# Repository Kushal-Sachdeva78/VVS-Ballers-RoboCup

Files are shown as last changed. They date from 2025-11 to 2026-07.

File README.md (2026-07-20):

<p align="center">
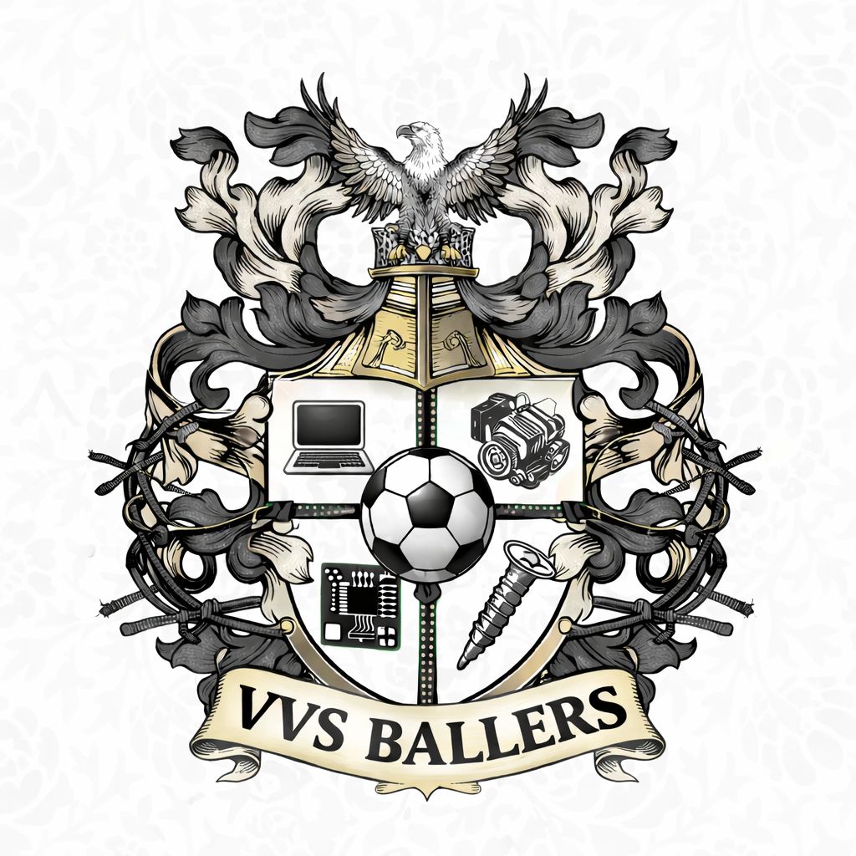
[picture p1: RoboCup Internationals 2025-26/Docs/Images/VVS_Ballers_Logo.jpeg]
VVS Ballers
  
</p>

<h1 align="center">VVS Ballers: RoboCupJunior Soccer</h1>

<p align="center">
  Autonomous RoboCupJunior Soccer robots by Team VVS Ballers, designed and iterated
  across multiple seasons, from EV3 regional robots to a custom Teensy-based
  international platform.<br>
  Firmware (C++) · multi-board electronics (KiCad) · mechanical design (Fusion 360).
</p>

<p align="center">
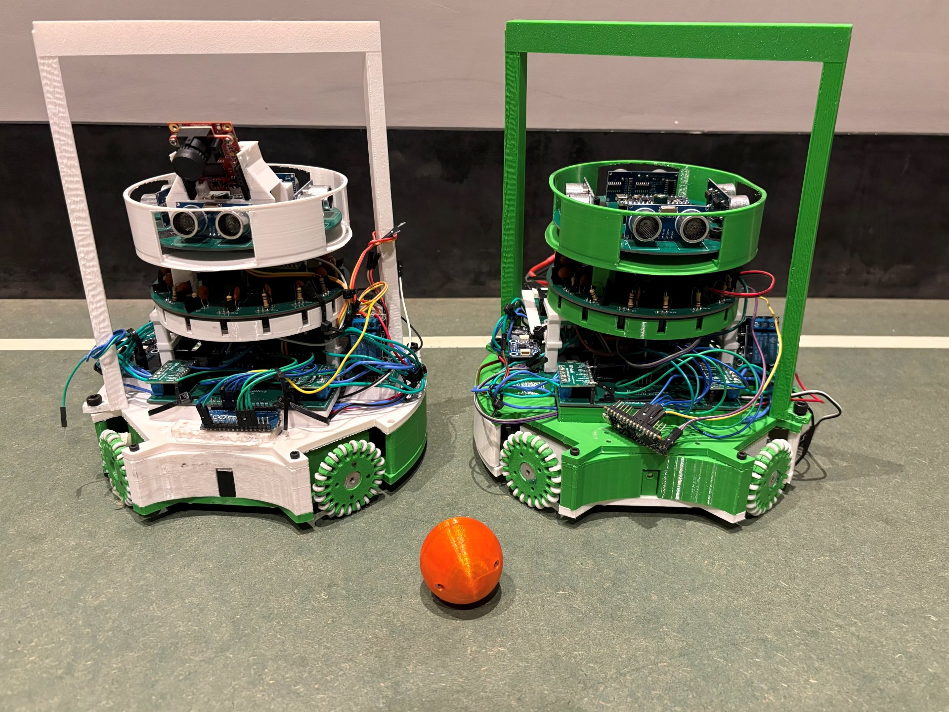
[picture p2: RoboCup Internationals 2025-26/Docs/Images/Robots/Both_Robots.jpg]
The two Internationals 2025-26 robots with the IR ball
  
</p>

---

## Results

- **RoboCup 2026, Incheon, South Korea (International): 9th place, RoboCupJunior Soccer (IR League).** Two self-built robots, designed, wired, and programmed by a team of two.
- **RoboCupJunior India, 2025-26 season**: came up through the Indian regional and national rounds to qualify for RoboCup 2026. The trophy and finals footage from the national event are in the [Nationals gallery](RoboCup%20Nationals%202025-26/Gallery).

## Press and media

- [Two Students, Two Self-Built Robots, And A 9th-Place Finish At The Robot "World Cup"](https://www.republicworld.com/sports/two-students-two-self-built-robots-and-a-ninth-place-finish-at-the-robot-world-cup-2026-07-14-132303) (Republic World, July 2026)
- [Team Instagram](https://www.instagram.com/vvs_ballers) - Robot builds, competition footage, and event coverage

---

## Seasons

| Season | What's inside |
|---|---|
| **[RoboCup Internationals 2025-26](RoboCup%20Internationals%202025-26/)** ⭐ *current* | Two autonomous Soccer-Infrared robots (attacker + defender): a Teensy 4.1 multi-board stack with an IR ball ring, line ring, ultrasonic, OpenMV goal camera, and 48 V solenoid kicker. Firmware + KiCad PCBs + Fusion CAD. |
| **[RoboCup Nationals 2025-26](RoboCup%20Nationals%202025-26/)** | Nationals build: EV3 robot program (HiTechnic IR seeker and compass), an Arduino relay-driven solenoid kicker, 3D-printed chassis parts, the season poster, and the trophy and finals gallery. |
| **[RoboCup Regionals 2025-26](RoboCup%20Regionals%202025-26/)** | EV3 holonomic robot (diamond omni drive, dual underside colour sensors, side IR distance, IR seeker, compass heading hold) + an Arduino ultrasonic-triggered kicker + printable parts + poster. |
| **[RoboCup 2024-25](RoboCup%202024-25/)** | Prior season: international Team Description Paper, posters, and earlier EV3 reference designs. |

> The **Internationals 2025-26** robots are the current flagship, and the rest of this
> page focuses on them. The full detail lives in that folder's
> **[detailed README](RoboCup%20Internationals%202025-26/README.md)** and a complete
> **[technical deep-dive](RoboCup%20Internationals%202025-26/Docs/HOW_IT_WORKS.md)**.
> Competition media: **[TDP](RoboCup%20Internationals%202025-26/Docs/TDP.md)** ·
> **[poster](RoboCup%20Internationals%202025-26/Docs/RoboCup_Internationals_Poster.png)** ·
> **[TDP video](https://github.com/Kushal-Sachdeva78/VVS-Ballers-RoboCup/releases/download/internationals-2025-26-media/VVS_Ballers_TDP_Video.mp4)** ·
> **[photo gallery](RoboCup%20Internationals%202025-26/Docs/Images)**.
>
> Code-span paths below (e.g. `Firmware/Attacker`) are relative to
> [`RoboCup Internationals 2025-26/`](RoboCup%20Internationals%202025-26/).

### Earlier-season highlights

- **Regionals 2025-26 (EV3):** EV3 motors driving omni wheels in a **diamond** layout;
  underside colour sensors for white-line and goal-area avoidance; side IR sensors for
  walls; an IR seeker for ball tracking; and a compass for heading correction. An
  external Arduino kicker (TB6612FNG H-bridge + gearmotor, ultrasonic ball detect)
  steps through kick, hold, retract, and cooldown phases.
- **Nationals 2025-26 (EV3):** the same EV3 sensing platform, upgraded with a
  relay-driven solenoid kicker triggered by an ultrasonic capture sensor. The custom
  Teensy and KiCad electronics stack was developed next, for the Internationals robots.

---

## Internationals 2025-26: the robots at a glance

Both robots share one electronics stack and one chassis; only the role firmware on
the main board differs.

| | Attacker | Defender (goalkeeper) |
|---|---|---|
| Job | Win the ball, aim, and shoot the open corner | Hold the goal mouth and clear the ball |
| Main firmware | `Firmware/Attacker/Attacker_Chase_Aim_Kick_Line` | `Firmware/Defender/Defender_Full` |
| Ball | IR ring (16 sensors) | IR ring |
| Staying in bounds | **Line ring + ultrasonic fused** boundary escape | **Line** keeps it on the goal-area ("D") line; ultrasonic cross-check |
| Goal / aim | OpenMV camera to open-corner bearing | (camera optional) |
| Kicker | 48 V solenoid, camera-gated | Short clearing kick |

## Electronics: the boards

A **multi-board design**: each subsystem has its own microcontroller, and the boards
talk to the main board over compact **UART links** (CRC-8-framed, bar the plain-ASCII
IR link), keeping the fast sensor loops off the main control CPU.

| Board | MCU | Does | KiCad | Firmware |
|---|---|---|---|---|
| **Main** | Teensy 4.1 | Drive (4x DRV8263H), BNO055 IMU, capture sensor, kicker relay, all links | `PCB/Main` | `Firmware/Attacker`, `Firmware/Defender` |
| **IR ring** | Teensy 4.1 | 16x TSSP58038 for ball bearing and distance | `PCB/IR` | `Firmware/IR_Ball_Sensor` |
| **Line ring** | Teensy 4.1 | 4x QTR-MD-05A (18 ch) for white-line detection | `PCB/Line` | `Firmware/Line_Sensor` |
| **Ultrasonic** | Arduino Nano Every | 4x HC-SR04 for wall distances | `PCB/Ultrasonic` | `Firmware/Ultrasonic` |
| **Camera** | OpenMV H7 | Goal / keeper / open-corner vision | - | `Firmware/Camera` |
| **Power** | - | 12 V / 5 V / 3.3 V rails + 48 V solenoid boost | `PCB/Power` | - |
| **Motor-current** (optional) | Arduino Nano Every | DRV8263H stall / over-current watchdog | - | `Firmware/Motor_Current` |

Human-readable wiring PDFs for the Main, Power, IR, and Line boards are in
**[`PCB/Wiring/`](RoboCup%20Internationals%202025-26/PCB/Wiring)**.

## How it plays: design choices vs. the game

Everything is built around what actually wins (and loses) a RoboCupJunior Soccer
match. (A goal counts when the ball touches the **back wall of the goal**; touching a
wall or driving fully into the marked penalty area is an **out-of-bounds penalty**.)

- **Score in the goal.** The IR ring gives the ball's bearing; the main board chases
  it with an omni-wheel drive held straight by a BNO055 heading PID. Once the ball is
  captured, the OpenMV camera finds the goal, picks the **open corner** (dodging the
  keeper), and the chassis turns in place until that corner is dead ahead before the
  solenoid fires. Aiming for the open corner instead of the goal centre is how you
  beat a keeper.

- **Never cross the line (the expensive mistake).** The attacker treats a side as the
  field boundary **only when the line ring and the ultrasonics agree** (white line
  seen *and* wall within 300 mm), then flees away from it. Two independent sensors
  must concur, so one noisy reading can't make the robot dart out of bounds.

- **Keep the keeper on its line, not inside the box.** No robot may be *fully* inside
  the penalty area, so the defender uses the line ring to ride the **edge of the goal
  area ("the D")** while tracking the ball laterally and clearing it on contact.

- **Stay legal in the Infrared league.** IR-emitting rangefinders (ToF, LiDAR, IR
  distance sensors) are **banned** because they'd swamp other robots' IR ball
  sensors. That is why walls are ranged with **ultrasonic** HC-SR04s here, not IR.

- **Power within the rules.** The rules cap robot power at **48 V DC**; the solenoid
  kicker runs from a 48 V boost converter (right at the legal ceiling, for the hardest
  legal kick) while logic and motors run from 3.3 V / 5 V / 12 V rails.

- **Referee start/stop.** The main board pins out the RoboCupJunior **Communication
  Module** GO/STOP inputs, with firmware support toggled via `USE_COMMS` in the
  defender build.

The binary inter-board links (ultrasonic, line, camera to main) are short frames, each
guarded by an identical **CRC-8 (poly 0x07)**; the IR link is plain delimited ASCII.
Full byte-level layouts are in the
[technical deep-dive](RoboCup%20Internationals%202025-26/Docs/HOW_IT_WORKS.md).

## Team

| Member | Roles |
|---|---|
| **Kushal Sachdeva** (Team Leader) | Electrical, Software & CAD |
| **Darsh Goel** | Mechanical & CAD |

Region: **India** · League: **RoboCupJunior Soccer Infrared**

## Sponsors

Our thanks to **Amazon · DLF · Havells · OpenMV · Magnum Ventures · Budtree
Management**, and to our mentors, school, and the RoboCup Junior community for their
support.

## Related projects

- [K.A.D-Ballers-Genius-Olympiad](https://github.com/Kushal-Sachdeva78/K.A.D-Ballers-Genius-Olympiad): our mecanum-drive robot for the GENIUS Olympiad robotics competition
- More at [github.com/Kushal-Sachdeva78](https://github.com/Kushal-Sachdeva78)

## License

Released under the **MIT License**; see [`LICENSE`](LICENSE).
© 2026 VVS Ballers (Kushal Sachdeva, Darsh Goel). You're welcome to learn from and
build on this work; please keep the attribution.

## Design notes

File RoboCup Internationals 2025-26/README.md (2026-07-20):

<p align="center">
  VVS Ballers
</p>

<h1 align="center">VVS Ballers — RoboCupJunior Soccer (Internationals 2025-26)</h1>

<p align="center">
  Two fully autonomous robots — an <b>attacker</b> and a <b>defender</b> — for the
  <b>RoboCupJunior Soccer Infrared</b> (formerly Lightweight) league.<br>
  Firmware(C++) · multi-board electronics (KiCad) · mechanical design (Fusion 360).
</p>

<p align="center">
  The two robots — one white, one green — facing off over the IR ball
</p>

---

## About

This folder is the **Internationals 2025-26** season of the VVS Ballers
RoboCupJunior Soccer robots — the firmware that runs them, the PCBs that make up
their electronics, and the CAD for their chassis. The robots chase an infrared-emitting ball, find the goal with a
camera, kick with a solenoid, and stay inside the field using a line-sensor ring
backed up by ultrasonic ranging.

In **RoboCupJunior Soccer**, two teams of two robots play autonomous soccer on a
green field with white boundary lines. A goal is scored when the ball touches the
**back wall of the goal**; touching a wall or driving fully into the marked
penalty area is an **out-of-bounds penalty**. Every design decision here
is made against those facts — score in the goal, never cross the line, stay legal.
(See [How the robot works](Docs/HOW_IT_WORKS.md) for the full technical write-up.)

> **2026 ball note:** the Soccer Infrared league switched to the new 42 mm
> open-source [IR golf ball](https://github.com/robocup-junior/ir-golf-ball) — the
> same size as the Vision-league golf ball. The IR ring firmware here is tuned for it.

## Competition documents & media

| | |
|---|---|
| 📄 **Team Description Paper** | [`Docs/TDP.md`](Docs/TDP.md) |
| 🎬 **TDP video** | [Watch / download](https://github.com/Kushal-Sachdeva78/VVS-Ballers-RoboCup/releases/download/internationals-2025-26-media/VVS_Ballers_TDP_Video.mp4) (154 MB, hosted under [Releases](https://github.com/Kushal-Sachdeva78/VVS-Ballers-RoboCup/releases)) |
| 🖼️ **Poster** | [`Docs/RoboCup_Internationals_Poster.png`](Docs/RoboCup_Internationals_Poster.png) |
| 🎤 **Group-interview deck** | [`Docs/VVS_Ballers_GroupInterview_Deck.pptx`](Docs/VVS_Ballers_GroupInterview_Deck.pptx) |
| 📊 **Block diagram & BOM** | [`Docs/VVS_Ballers_Electronics_Block_Diagram.png`](Docs/VVS_Ballers_Electronics_Block_Diagram.png) · [`Docs/VVS_Ballers_BOM.xlsx`](Docs/VVS_Ballers_BOM.xlsx) |
| 📷 **Photo gallery** | [`Docs/Images/`](Docs/Images) — robots · electronics · mechanical · diagrams · team |

<p align="center">
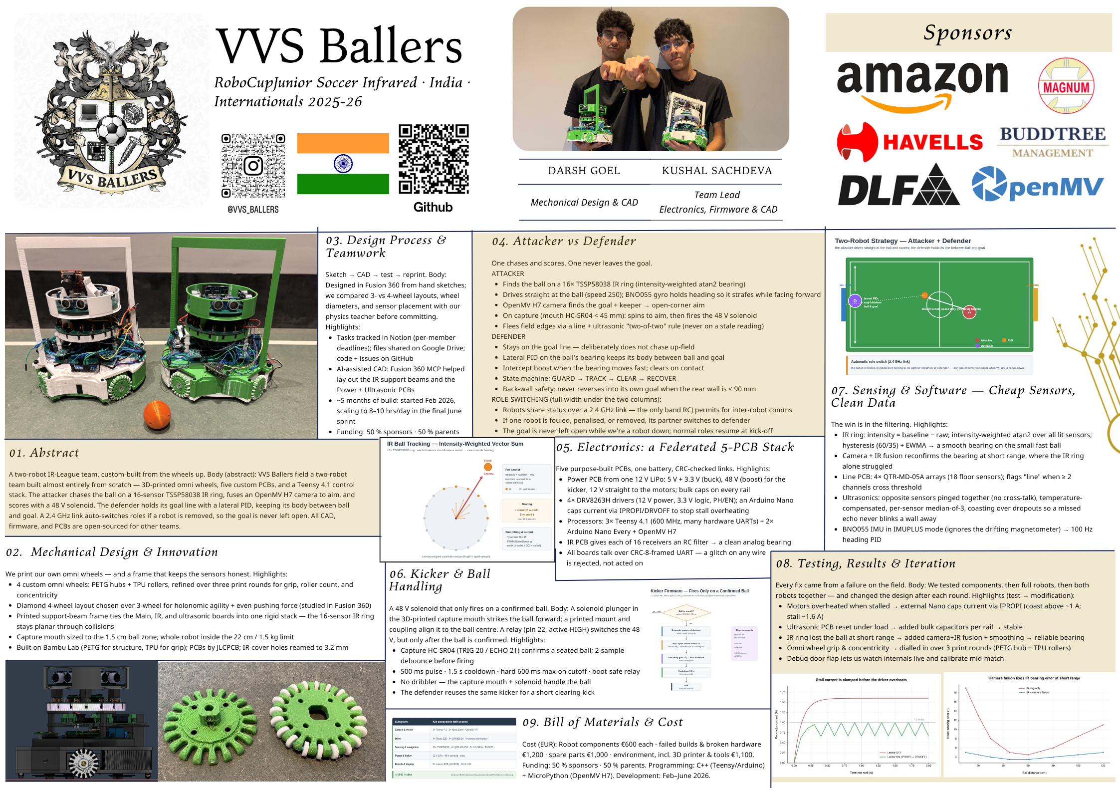
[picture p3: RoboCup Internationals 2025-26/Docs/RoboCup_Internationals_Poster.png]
RoboCup Internationals 2025-26 poster
  
</p>

## Team

| Member | Roles |
|---|---|
| **Kushal Sachdeva** (Team Leader) | Electrical, Software & CAD |
| **Darsh Goel** | Mechanical & CAD |

Region: **India** · League: **RoboCupJunior Soccer Infrared**

<p align="center">
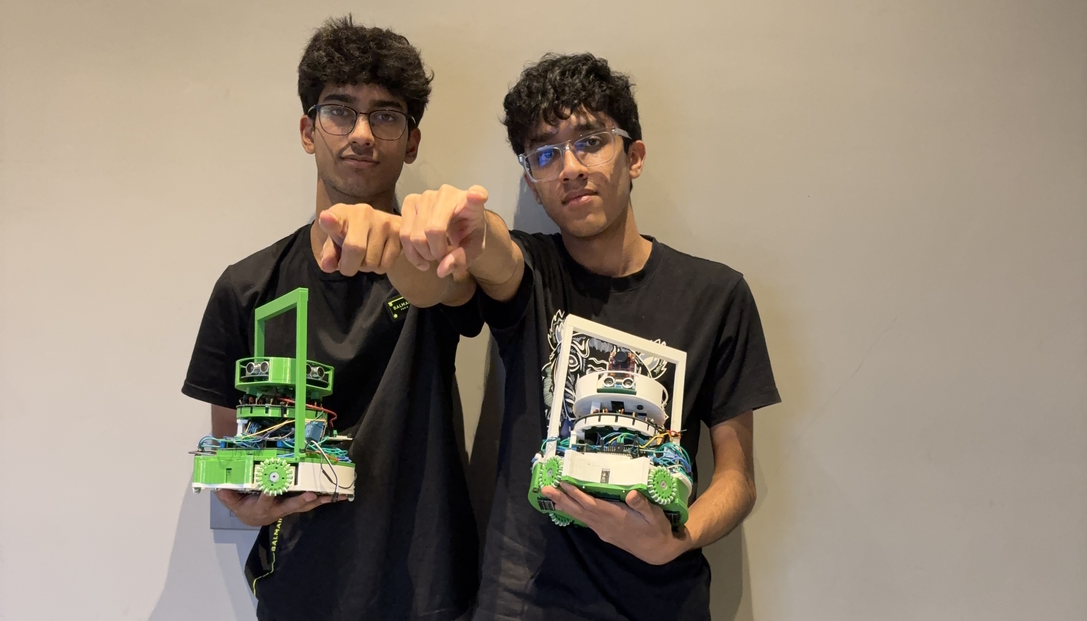
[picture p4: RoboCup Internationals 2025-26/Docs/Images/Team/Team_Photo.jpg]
Team VVS Ballers
  
</p>

## The robots at a glance

Both robots share one electronics stack and one chassis; only the role firmware on
the main board differs.

| | Attacker | Defender (goalkeeper) |
|---|---|---|
| Job | Win the ball, aim, and shoot the open corner | Hold the goal mouth and clear the ball |
| Main firmware | `Firmware/Attacker/Attacker_Chase_Aim_Kick_Line` | `Firmware/Defender/Defender_Full` |
| Ball | IR ring (16 sensors) | IR ring |
| Staying in bounds | **Line ring + ultrasonic fused** boundary escape | **Line** keeps it on the goal-area ("D") line; ultrasonic cross-check |
| Goal / aim | OpenMV camera → open-corner bearing | (camera optional) |
| Kicker | 48 V solenoid, camera-gated | Short clearing kick |

## Electronics — the boards

The robot is a **multi-board design**: each subsystem has its own microcontroller,
and the boards talk to the main board over compact **UART links** (CRC-8-framed, bar
the plain-ASCII IR link). This keeps
the fast sensor loops off the main control CPU.

| Board | MCU | Does | KiCad | Firmware |
|---|---|---|---|---|
| **Main** | Teensy 4.1 | Drive (4× DRV8263H), BNO055 IMU, capture sensor, kicker relay, all links | `PCB/Main` | `Firmware/Attacker`, `Firmware/Defender` |
| **IR ring** | Teensy 4.1 | 16× TSSP58038 → ball bearing & distance | `PCB/IR` | `Firmware/IR_Ball_Sensor` |
| **Line ring** | Teensy 4.1 | 4× QTR-MD-05A (18 ch) → white-line detection | `PCB/Line` | `Firmware/Line_Sensor` |
| **Ultrasonic** | Arduino Nano Every | 4× HC-SR04 → wall distances | `PCB/Ultrasonic` | `Firmware/Ultrasonic` |
| **Camera** | OpenMV H7 | Goal / keeper / open-corner vision | — | `Firmware/Camera` |
| **Power** | — | 12 V / 5 V / 3.3 V rails + 48 V solenoid boost | `PCB/Power` | — |
| **Motor-current** (optional) | Arduino Nano Every | DRV8263H stall / over-current watchdog | — | `Firmware/Motor_Current` |

Wiring for every board is in **[`PCB/Wiring/`](PCB/Wiring)** (one PDF per board) and
explained in [How the robot works](Docs/HOW_IT_WORKS.md). A whole-robot
[electronics block diagram](Docs/VVS_Ballers_Electronics_Block_Diagram.png) and the
full [bill of materials](Docs/VVS_Ballers_BOM.xlsx) live in `Docs/`.

<p align="center">
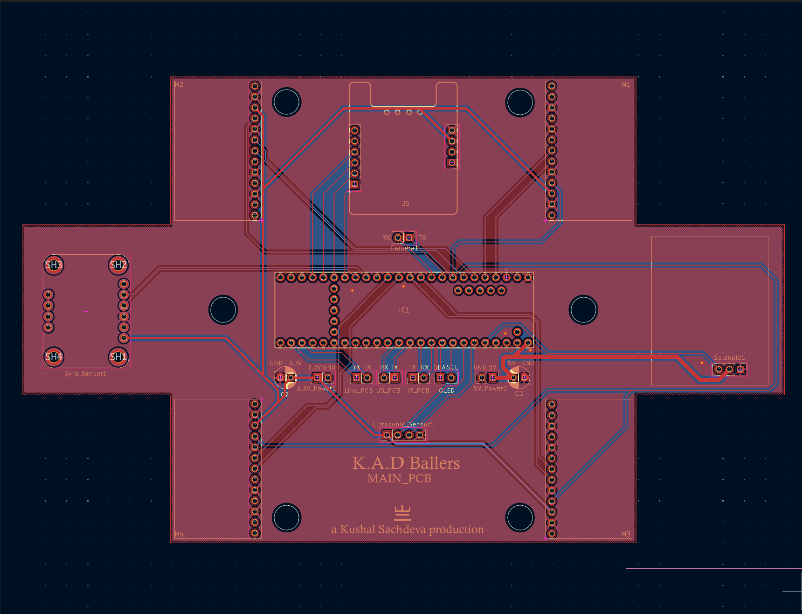
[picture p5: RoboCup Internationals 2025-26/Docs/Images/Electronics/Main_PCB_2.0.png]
Main PCB 2.0
  
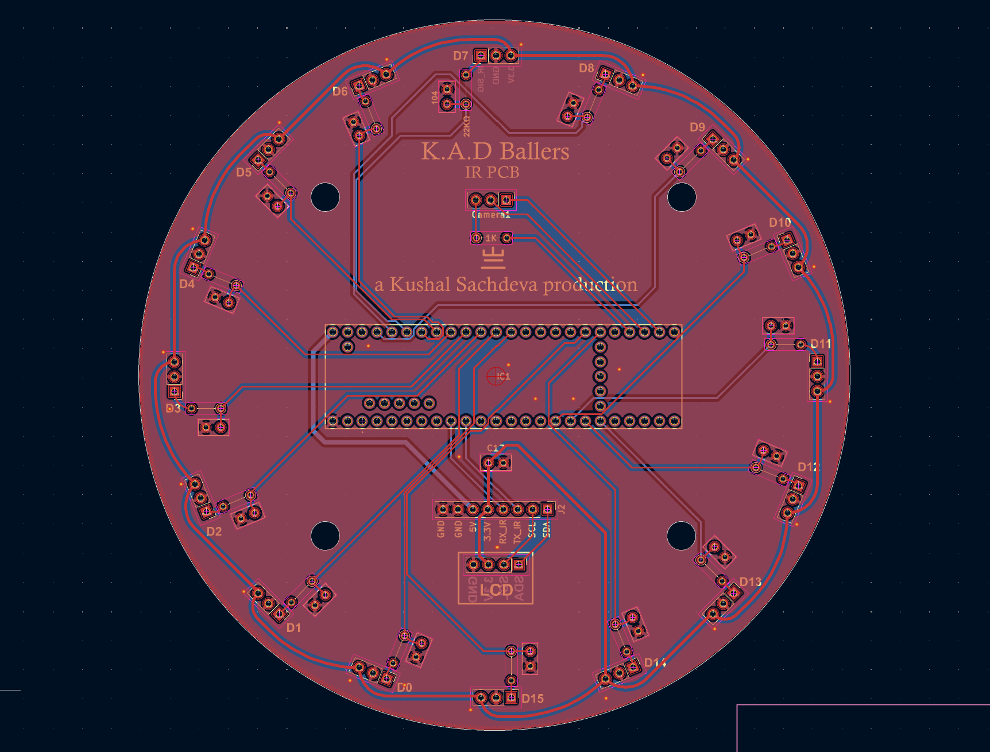
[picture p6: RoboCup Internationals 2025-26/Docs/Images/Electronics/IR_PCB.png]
IR ring PCB
  
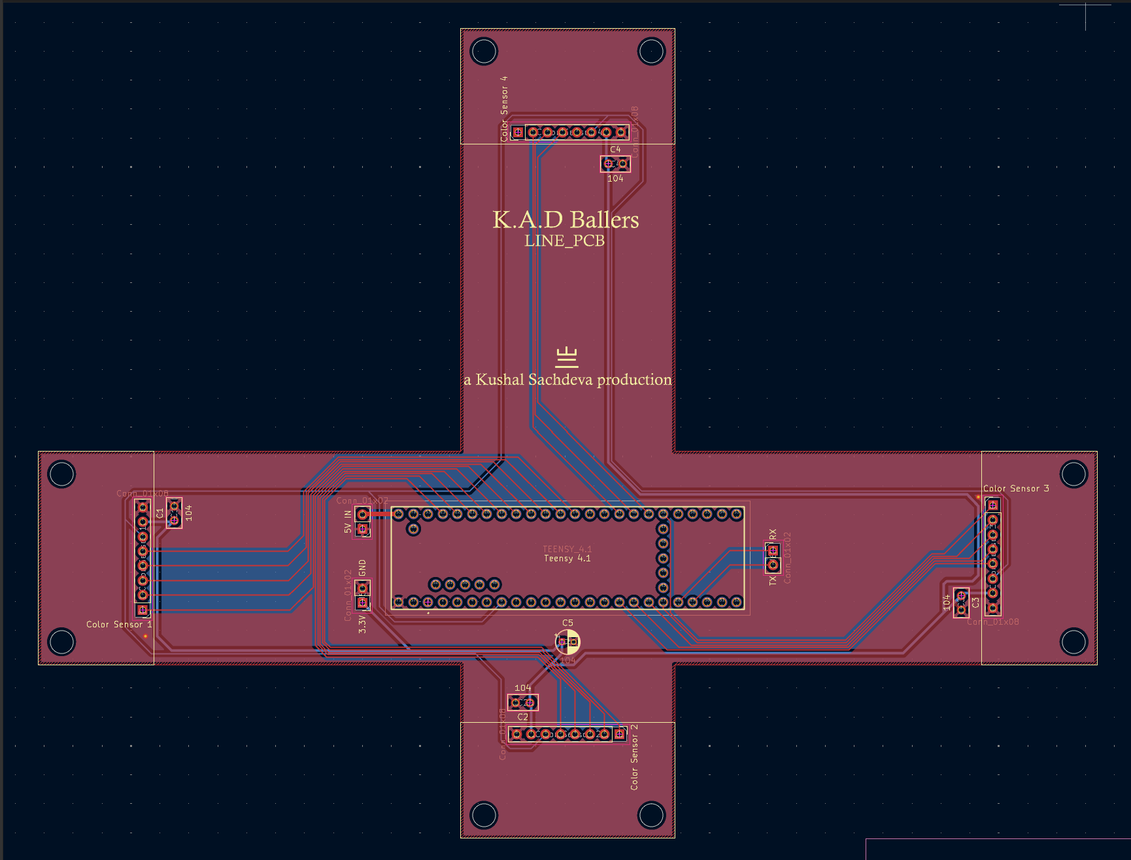
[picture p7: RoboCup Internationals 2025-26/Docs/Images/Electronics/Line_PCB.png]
Line ring PCB
  
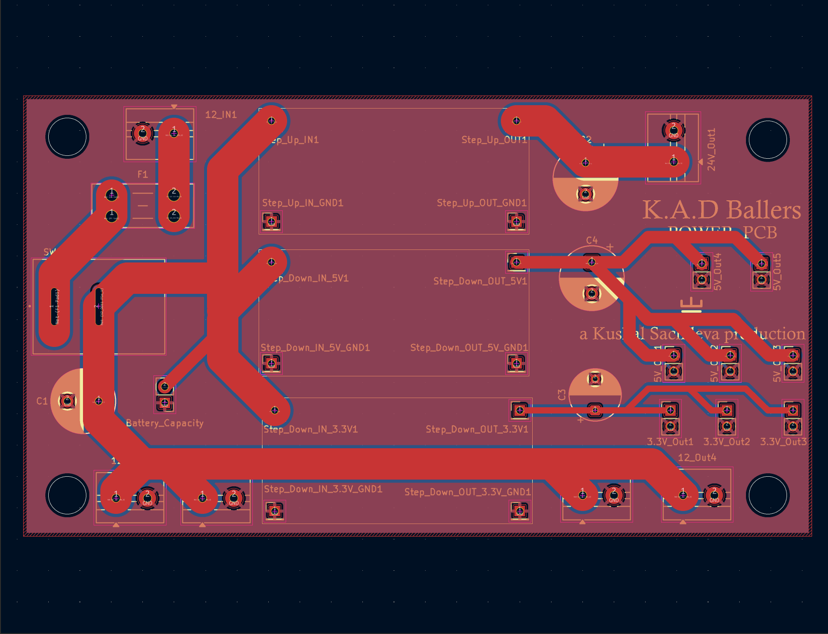
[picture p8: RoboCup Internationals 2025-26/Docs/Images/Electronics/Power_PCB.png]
Power PCB
  
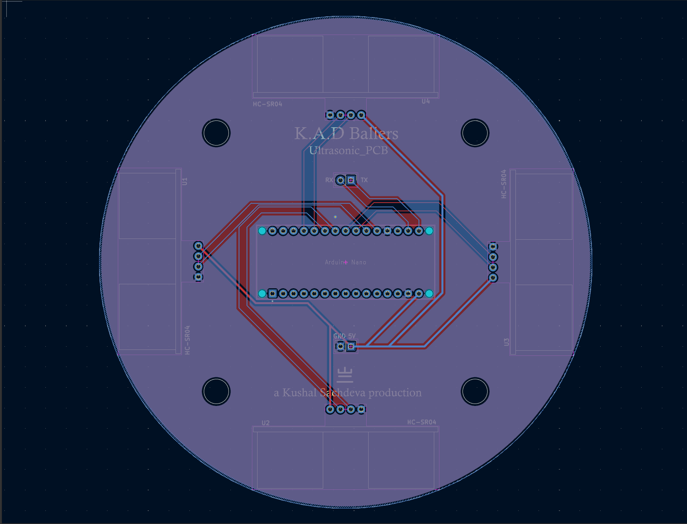
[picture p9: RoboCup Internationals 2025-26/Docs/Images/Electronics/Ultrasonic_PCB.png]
Ultrasonic PCB
  
</p>
<p align="center"><i>The five boards — Main 2.0 · IR ring · Line ring · Power · Ultrasonic
(KiCad renders; build photos in <a href="Docs/Images/Electronics">Docs/Images/Electronics</a>)</i></p>

## How it plays — design choices vs. the game

Everything here is built around what actually wins (and loses) a RoboCupJunior
Soccer match:

- **Score in the goal.** The IR ring gives the ball's bearing; the main board chases
  it with an omni-wheel drive held straight by a BNO055 heading PID. Once the ball
  is captured, the OpenMV camera finds the goal, picks the **open corner** (dodging
  the keeper), and the chassis turns in place until that corner is dead ahead before
  the solenoid fires. Aiming the open corner instead of the goal centre is how you
  beat a keeper.

- **Never cross the line (the expensive mistake).** Touching a wall *or* driving
  fully into the marked penalty area is an **out-of-bounds penalty** — the robot is
  removed for a minute, and any goal scored while it's penalised is wiped. The
  attacker therefore treats a side as the field boundary **only when the line ring
  and the ultrasonics agree** (white line seen *and* wall within 300 mm), then flees
  away from it. Two independent sensors must concur, so one noisy reading can't make
  the robot dart out of bounds.

- **Keep the keeper on its line, not inside the box.** No robot may be *fully* inside
  the penalty area (that's out of bounds), so the defender uses the line ring to ride
  the **edge of the goal area ("the D")** — staying on the line rather than crossing
  it — while tracking the ball laterally and clearing it on contact.

- **Stay legal in the Infrared league.** IR-emitting rangefinders (ToF, LiDAR, IR
  distance sensors) are **banned** in the Infrared league because they'd swamp other
  robots' IR ball sensors — which is exactly why walls are ranged with **ultrasonic**
  HC-SR04s here, not IR. The reflectance line sensors face **down at the floor** and
  are shrouded so their light can't be mistaken for the orange ball by other teams'
  cameras.

- **Power within the rules.** The rules cap robot power at **48 V DC**; the solenoid
  kicker runs from a 48 V boost converter — right at the legal ceiling for the
  hardest legal kick — while logic and motors run from 3.3 V / 5 V / 12 V rails.

- **Referee start/stop.** The main board reads the RoboCupJunior **Communication
  Module** GO/STOP lines, so a referee can start and halt the robot as the rules
  require at the international competition.

## Folder structure

```
RoboCup Internationals 2025-26/
├─ README.md                  ← you are here
├─ Docs/
│  ├─ HOW_IT_WORKS.md         ← full technical deep-dive
│  ├─ MAPPING.md              ← original → new file/folder mapping
│  ├─ TDP.md                  ← Team Description Paper (Markdown)
│  ├─ TDP_images/             ← images embedded in TDP.md
│  ├─ RoboCup_Internationals_Poster.png
│  ├─ VVS_Ballers_GroupInterview_Deck.pptx
│  ├─ VVS_Ballers_BOM.xlsx    ← bill of materials
│  ├─ VVS_Ballers_Electronics_Block_Diagram.png
│  └─ Images/                 ← gallery: Robots · Electronics · Mechanical · Diagrams · Team
├─ Firmware/                  ← all microcontroller code
│  ├─ Attacker/               ← main-board attacker (current: …_Line)
│  ├─ Defender/               ← main-board goalkeeper (Defender_Full)
│  ├─ IR_Ball_Sensor/         ← IR ring (Code2_Calibrated = flight build)
│  ├─ Line_Sensor/            ← QTR line ring (Detect / Baseline / Raw)
│  ├─ Ultrasonic/             ← Nano Every HC-SR04 board + main-board parser
│  ├─ Camera/                 ← OpenMV H7 goal vision (MicroPython)
│  ├─ Motor_Current/          ← optional over-current watchdog
│  └─ README.md
├─ PCB/                       ← KiCad sources, Gerbers, wiring PDFs, fab zips
│  ├─ Main/ IR/ Line/ Ultrasonic/ Power/
│  ├─ Wiring/        ← human-readable wiring per board (PDF)
│  ├─ Fabrication/   ← ready-to-order Gerber zips
│  └─ README.md
├─ CAD/                       ← Fusion 360 sources + printable STLs
│  ├─ Fusion/   Printable/{Chassis, Drive, Ball_Capture, Sensor_Mounts}
│  └─ README.md
└─ Legacy/                    ← superseded designs, kept for history (see Legacy/README.md)
```

## Build & flash

All boards build in the **Arduino IDE** (each sketch folder is named to match its
`.ino`); the Teensy/Nano sketches also build under **PlatformIO** via the
`platformio.ini` in each folder.

| Target | Board setting | Libraries / notes |
|---|---|---|
| Main board (attacker/defender) | Teensy 4.1, USB Type *Serial* | Adafruit BNO055 + Adafruit Unified Sensor (Defender OLED option also needs SSD1306 + GFX) |
| IR ring | Teensy 4.1 | none (core `analogRead`) — flash `Code2_Calibrated` |
| Line ring | Teensy 4.1 | none |
| Ultrasonic | Arduino Nano Every (megaAVR) | none; *Registers emulation → None (ATMEGA4809)* |
| Motor-current | Arduino Nano Every | none |
| Camera | OpenMV H7 | save `Goal_Cam.py` to the H7 flash as `main.py` |

PlatformIO example: `pio run -e teensy41 -t upload` (Teensy) or
`pio run -e nano_every -t upload` (Nano).

## Inter-board links (summary)

Three of the four links are short binary frames with a 2-byte sync and an identical
**CRC-8 (poly 0x07)**, so the main board can reject any corrupted frame; the IR link
is plain delimited ASCII:

- **IR → Main** (Serial4): ASCII `"<dir>a … <dist>b"`, `500` = no ball (no checksum).
- **Ultrasonic → Main** (Serial3): 13-byte frame, four `uint16` mm distances + status.
- **Line → Main** (Serial8): 9-byte frame, per-side white-line bitmask + counts.
- **Camera → Main** (Serial2): 11-byte frame, goal/keeper/ball flags + bearings,
  open-corner angle, and the orange-ball bearing/distance (camera+IR fusion).

Full byte-level layouts are in [How the robot works](Docs/HOW_IT_WORKS.md).

## Sponsors

Our thanks to **Amazon · DLF · Havells · OpenMV · Magnum Ventures · Budtree
Management** for supporting the team.

## License

Released under the [MIT License](LICENSE) © 2026 VVS Ballers. You're welcome to
learn from and build on this work — please keep the attribution.

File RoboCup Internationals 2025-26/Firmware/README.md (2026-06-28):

# Firmware

All microcontroller code for the robot. Each sub-folder targets one board. Each
sketch folder is named to match its `.ino`, because the Arduino IDE requires the
folder name to match the sketch, and most folders also carry a `platformio.ini` for
PlatformIO.

See [`../Docs/HOW_IT_WORKS.md`](../Docs/HOW_IT_WORKS.md) for the full explanation of
each subsystem and the inter-board protocols.

| Folder | Board | Flash this | Status |
|---|---|---|---|
| `Attacker/Attacker_Chase_Aim_Kick_Line` | Main (Teensy 4.1) | ✅ current attacker | IR chase + fused line/ultrasonic boundary escape + camera aim + kick |
| `Defender/Defender_Full` | Main (Teensy 4.1) | ✅ current keeper | line-primary box keeper + ultrasonic + state machine |
| `IR_Ball_Sensor/Code2_Calibrated` | IR ring (Teensy 4.1) | ✅ flight build | calibration baked in (2026-06-27) |
| `IR_Ball_Sensor/Code2_Refined` | IR ring | reference | same code, uncalibrated defaults |
| `IR_Ball_Sensor/Calibration` | IR ring | tool | baseline capture + Serial-Plotter readout |
| `Ultrasonic/Ultrasonic_NanoEvery` | Ultrasonic (Nano Every) | ✅ board firmware | 4× HC-SR04, opposite-pair pinging |
| `Ultrasonic/Ultrasonic_Receiver_MainBoard` | Main | reference | drop-in parser for the main firmware |
| `Line_Sensor/Line_PCB_Baseline` | Line ring (Teensy 4.1) | ✅ auto-learn detector | 1 s green baseline, then drop-by-5 |
| `Line_Sensor/Line_PCB_Detect` | Line ring | ✅ fixed-threshold detector | per-sensor thresholds + hysteresis |
| `Line_Sensor/Line_PCB_Raw_Reader` | Line ring | tool | raw ADC streamer for calibration |
| `Camera/Goal_Cam.py` | OpenMV H7 | ✅ match build | goal / keeper / open-corner vision |
| `Camera/Goal_Cam_Ball.py` | OpenMV H7 | diagnostic | same frame + orange-ball overlay |
| `Motor_Current/Motor_Current_Supervisor` | Nano Every (optional) | watchdog | stall-timer over-current protection |
| `Motor_Current/Motor_Current_Limit_1A` | Nano Every (optional) | watchdog | simple per-motor 1 A chop |
| `Comms/RobotLink` | Main (Teensy 4.1) + nRF24L01+ | optional link | inter-robot 2.4 GHz role switching — survivor covers the goal ([`Comms/README.md`](Comms/README.md)) |
| `RobotMain` | Main (Teensy 4.1) + nRF24L01+ | combined build | one flash that runs attacker OR defender live via RobotLink ([`RobotMain/README.md`](RobotMain/README.md)) |

Superseded no-line versions live in [`../Legacy/Firmware`](../Legacy/Firmware).

## Build quick-reference

- **Teensy 4.1** sketches: Arduino IDE → *Teensy 4.1*, USB Type *Serial*; or
  `pio run -e teensy41 -t upload`. The main board needs **Adafruit BNO055** +
  **Adafruit Unified Sensor** (and SSD1306 + GFX only if the Defender OLED option is
  enabled).
- **Nano Every** sketches: Arduino IDE → *Arduino Nano Every*, Registers emulation
  *None (ATMEGA4809)*; or `pio run -e nano_every -t upload`.
- **OpenMV H7:** copy `Goal_Cam.py` onto the camera's flash as `main.py`.

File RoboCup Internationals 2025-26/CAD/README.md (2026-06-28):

# CAD

Mechanical design for the chassis, done in **Fusion 360**.

| Folder | Contents |
|---|---|
| `Fusion/` | Fusion sources — `.f3z` archives (full assemblies + version history) and `.f3d` designs. |
| `Printable/` | 3D-print-ready meshes (`.stl`, `.3mf`), grouped **by subsystem**: `Chassis/`, `Drive/`, `Ball_Capture/`, `Sensor_Mounts/`. |

Older/superseded chassis, motor-bracket and support-beam studies are in
[`../Legacy/CAD`](../Legacy/CAD).

## Notes

- **Large files / Git LFS.** The `.f3z` archives are large (the full-robot versions
  are ~66 MB each). This repo tracks `.f3z`, `.f3d`, `.step`, `.stl` and `.3mf`
  through **Git LFS** (see [`../.gitattributes`](../.gitattributes)); run
  `git lfs install` once before cloning or committing.
- **What prints what.** `Printable/` is organised by subsystem:
  - `Chassis/` — side walls, base / top base, support beams, lifting handle.
  - `Drive/` — omni wheels, rollers, couplings.
  - `Ball_Capture/` — the capture-area dribbler mouth (all iterations).
  - `Sensor_Mounts/` — IR cover, camera holders, ultrasonic holders/plates.
- The **capture area** is sized to keep the ball within the rules' ≤ 1.5 cm
  ball-capturing-zone limit; the **handle** satisfies the rules' handle/clearance
  requirement.

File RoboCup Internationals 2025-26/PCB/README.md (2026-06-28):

# PCB

KiCad sources, Gerbers, drill and job files for every board, plus human-readable
wiring and ready-to-order fab packages.

| Folder | Board | Contents |
|---|---|---|
| `Main/` | Main board (Teensy 4.1 carrier) | KiCad source + Gerbers — drivers, IMU, links, kicker relay (Main_PCB 2.0) |
| `IR/` | IR ball ring | 16× TSSP58038 + Teensy |
| `Line/` | Line ring | 4× QTR-MD-05A + Teensy |
| `Ultrasonic/` | Ultrasonic board | 4× HC-SR04 + Nano Every |
| `Power/` | Power board | 12 V / 5 V / 3.3 V rails + 48 V solenoid boost |
| `Wiring/` | — | **one wiring PDF per board** (the netlist in plain language) |
| `Fabrication/` | — | ready-to-order Gerber **zips** |

The previous main board revision is archived in
[`../Legacy/PCB/Main_v1`](../Legacy/PCB/Main_v1).

## Opening the sources

Each board folder is a KiCad project — open the `*.kicad_pro` (the matching
`.kicad_pcb` and `.kicad_sch` sit beside it). The loose `*.gbr` / `*.drl` /
`*.gbrjob` files are **generated** fabrication outputs; for ordering, prefer the
zipped packages in [`Fabrication/`](Fabrication). KiCad local-settings files
(`*.kicad_prl`) and auto-backups are intentionally git-ignored.

## Start with the wiring PDFs

If you only read one thing, read [`Wiring/`](Wiring): `Main_PCB.pdf`, `Power_PCB.pdf`,
`IR_PCB.pdf`, and `Line_PCB.pdf` list every connection (rails, sensor pins, UART
links) in plain language. They are the reference the firmware pin maps were verified
against.

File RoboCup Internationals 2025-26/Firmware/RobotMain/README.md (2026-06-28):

# RobotMain — combined firmware (one build, either role)

The single firmware that makes inter-robot role switching real: it runs **both**
behaviours and lets [`RobotLink`](../Comms/RobotLink) pick which one each loop.

> partner alive → play your base role · partner lost → **cover the goal as keeper**

Flash the **same** sketch to both robots; they differ only by two `#define`s.

## Files

| File | What it is |
|---|---|
| `RobotMain.ino` | Thin dispatcher: `RobotLink.update()` → run `attackerLoop()` or `defenderLoop()`, and safe-stop the outgoing role on a switch. |
| `Roles.h` | Declares the role entry points. |
| `AttackerRole.cpp` | The attacker body, **generated** from `../Attacker/Attacker_Chase_Aim_Kick_Line`, wrapped in an anonymous namespace. |
| `DefenderRole.cpp` | The defender body, **generated** from `../Defender/Defender_Full` (its `config.h` inlined). |
| `RobotLink.h` / `.cpp` | A bundled copy of the radio module (canonical source: `../Comms/RobotLink`). |

The two `*Role.cpp` are **generated copies** — they're wrapped in anonymous
namespaces so the two sketches' identical globals (`setMotor`, `us_crc8`, …) and
clashing `#define`s (`CAPTURE_BALL_MM` 45 vs 50, the two kicker tables) stay
isolated and link cleanly. Edit the **canonical** Attacker/Defender sketches and
regenerate these, not the copies.

## Set up per robot

1. In **`RobotLink.h`** set, on each robot:
   ```c
   #define MY_ROBOT_ID   0               // 0 on one robot, 1 on the other
   #define MY_BASE_ROLE  ROLE_ATTACKER   // ATTACKER on one, DEFENDER on the other
   ```
2. Install the **RF24** library (TMRh20). Wire the nRF24L01+ on **SPI1** (CE/CSN
   per `RobotLink.h`, all `>>> BENCH-VERIFY`'d) with a 10 µF cap across its VCC/GND.
3. Build for **Teensy 4.1** and flash the same sketch to both robots.

> **Compile once in the Arduino IDE before flashing.** This combined build is new —
> open `RobotMain.ino`, verify it builds, and run the
> [bench test](../Comms/README.md#7-bench-test-procedure). Your standalone
> `Attacker_Chase_Aim_Kick_Line` and `Defender_Full` sketches are untouched and
> remain the per-role builds.

## How dispatch works

- `setup()` initialises **both** role units once (they share one chassis; only the
  active role drives each pass).
- Each loop: `RobotLink.update()` arbitrates the role; the dispatcher runs that
  role's loop. On a role change it calls the **outgoing** role's `…SafeStop()`
  (motors off + solenoid released) so nothing is left latched across the switch.
- No nRF24 fitted, or it fails to init → each robot plays its static `MY_BASE_ROLE`
  (graceful degradation; the robot never stalls).

See [`../Comms/README.md`](../Comms/README.md) for the link protocol, arbitration
rules, fail-safe details, and the bench-test procedure.

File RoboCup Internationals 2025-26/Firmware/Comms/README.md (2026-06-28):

# Comms — inter-robot role switching (`RobotLink`)

A peer-to-peer **2.4 GHz nRF24L01+** link that lets the two robots share one
firmware and pick their role at runtime:

> **partner alive → play your base role · partner lost → cover the goal as keeper**

So if a robot dies or is removed, its partner drops to goalkeeper within
`PARTNER_TIMEOUT_MS` and the net is never left open. When the partner returns, a
base-attacker resumes attacking at the next referee **GO** (kick-off).

- **Module:** [`RobotLink/RobotLink.h`](RobotLink/RobotLink.h) +
  [`RobotLink/RobotLink.cpp`](RobotLink/RobotLink.cpp)
- **Scaffold:** [`RoleDispatch_Example/RoleDispatch_Example.ino`](RoleDispatch_Example/RoleDispatch_Example.ino)
- **Library required:** RF24 (TMRh20) — <https://github.com/nRF24/RF24>

> Radio pins, the RF channel, and the timings are marked `>>> BENCH-VERIFY` in
> `RobotLink.h` — confirm them against Main_PCB_2.0 before wiring. A dead or absent
> radio is safe by design — see *Fail-safe* below.

> **RCJ compliance:** robot-to-robot only. No PC, phone, or access point in the
> link; 2.4 GHz peer-to-peer is the permitted inter-robot band.

---

## 1. Hardware / wiring

One nRF24L01+ per main board, on **SPI1** — **not** SPI0, because SPI0's MOSI/MISO
(pins 11/12) are Motor 4.

| nRF24L01+ | Teensy 4.1 | Notes |
|---|---|---|
| MOSI | 26 | SPI1 MOSI · `>>> BENCH-VERIFY` |
| MISO | 39 | SPI1 MISO · `>>> BENCH-VERIFY` |
| SCK | 27 | SPI1 SCK · `>>> BENCH-VERIFY` |
| CE | 30 | free GPIO · `>>> BENCH-VERIFY broken out & free` |
| CSN | 31 | free GPIO · `>>> BENCH-VERIFY broken out & free` |
| VCC | 3V3 | **add a 10 µF cap across VCC/GND** (the module browns out on TX bursts otherwise) |
| GND | GND | common ground |
| IRQ | — | unused (we poll, non-blocking) |

Occupied main-board pins the radio must avoid: `2,3,4,5,6,7,8,9,10,11,12,14,15,16,
20,21,22,24,25,34`, plus Serial7/comms `28/29` and Wire1/OLED `18/19`. Confirm
26/27/30/31/39 are actually broken out on **Main_PCB_2.0** before wiring.

## 2. Config (in `RobotLink.h`)

Set **per robot** (the only difference between the two builds):

```c
#define MY_ROBOT_ID   0               // 0 on one robot, 1 on the other
#define MY_BASE_ROLE  ROLE_ATTACKER   // ROLE_ATTACKER on one, ROLE_DEFENDER on the other
```

Shared tunables (both robots identical): `RF_CHANNEL`, `RF_ADDR_0/1`, `RF_CE_PIN`,
`RF_CSN_PIN`, `RF_SPI_*`, `HEARTBEAT_MS` (100), `PARTNER_TIMEOUT_MS` (750),
`ALIVE_DEBOUNCE_MS` (300), `PROMOTE_RESUME_MS` (3000). All are documented and
bench-flagged in the header.

## 3. Wire protocol (house framing)

8-byte payload, same convention as the wired links — 2-byte sync, little-endian
body, rolling seq, CRC-8 (poly 0x07, init 0x00 = `us_crc8`). The nRF's own
hardware CRC runs underneath as a second integrity layer.

```
[0]=0xC3 [1]=0x3C [2]=robotId [3]=baseRole [4]=currentRole [5]=state [6]=seq [7]=crc8(over [2..6])
  state: bit0 = alive/running (room to grow: ballSeen, kicking, etc.)
```

## 4. Integrating into the existing firmware

The current role is compile-time (you flash attacker XOR defender). To make it a
**runtime** variable, wrap each existing `loop()` body in a function and let
`RobotLink.role()` pick:

1. Copy `RobotLink.h` / `RobotLink.cpp` next to your main sketch (or install as a
   library) and `#include "RobotLink.h"`.
2. In `setup()`: call `RobotLink.begin();` **once** (it's non-blocking and safe
   even if the module is missing). Keep your existing sensor/motor init.
3. Refactor the two behaviours into functions (no logic changes):
   - `runAttacker()` ← the body of `Attacker_Chase_Aim_Kick_Line.ino` `loop()`
   - `runDefender()` ← the body of `Defender_Full.ino` `loop()`
   Shared init (motor pins, BNO055, IR/US/line/camera links, kicker) should run
   **once** in `setup()` — don't double-init a peripheral (e.g. call `bno.begin()`
   a single time). Role-specific-only init can stay in a per-role setup.
4. Dispatch each pass:

```c
void loop() {
  RobotLink.update();                       // non-blocking: rx + heartbeat + arbitrate
  RobotLink.setRefereeGo(commsRunning());   // optional: feed your GO/STOP reader

  if (RobotLink.role() == ROLE_ATTACKER) runAttacker();
  else                                   runDefender();   // also boot + fail-safe role
}
```

`RobotLink.update()` is non-blocking (no `delay()`); call it every pass. See
[`RoleDispatch_Example`](RoleDispatch_Example/RoleDispatch_Example.ino) for a
compilable skeleton.

> **Referee GO hook (recommended):** feeding `setRefereeGo()` the GO/STOP state
> means a base-attacker that dropped to keeper only **returns to attacking at the
> next kick-off**, not mid-play. If you never call it, `RobotLink` falls back to a
> timed resume (`PROMOTE_RESUME_MS`) once the partner is stable again.

## 5. Arbitration behaviour

| Situation | Role |
|---|---|
| Boot, no partner heard yet | **DEFENDER** (goal never open) |
| Partner alive | your `MY_BASE_ROLE` |
| Partner lost (`> PARTNER_TIMEOUT_MS`) | **DEFENDER**, immediately |
| Partner back, base = attacker | stay DEFENDER until the next GO edge (or timed resume) |
| Base = defender | always DEFENDER |

Demote-to-keeper is immediate (safety); promote-back is gated so roles can't flap
mid-play. The alive↔lost edge is debounced (`ALIVE_DEBOUNCE_MS`).

## 6. Fail-safe / graceful degradation

- **No partner yet →** DEFENDER (zero/default `Role` is the safe one).
- **Radio won't init (absent/dead/mis-wired) →** `radioOk()` is false and the
  robot runs its **static `MY_BASE_ROLE`** forever. It never blocks or stalls —
  you simply lose dynamic switching. This is explicit in `begin()`/`update()`.

## 7. Bench-test procedure

1. **Both robots powered, on a desk, ~1 m apart.** Open both USB serials. Confirm
   each reports `radio=ok`. The attacker-base robot should settle to `role=ATK`
   (after the GO edge / timed resume), the defender-base to `role=DEF`. Each should
   show `partner=alive`.
2. **Kill one robot** (power it down or pull its nRF24). Within
   `PARTNER_TIMEOUT_MS` (~0.75 s) the survivor must report `partner=LOST` and flip
   to `role=DEF`. Verify a base-attacker survivor is now the keeper.
3. **Restore the partner.** The survivor should report `partner=alive` again but
   **stay** `DEF` — it must **not** snap back to attacker on its own.
4. **Simulate kick-off:** drive `setRefereeGo(true)` (press GO, or temporarily
   hard-code a GO pulse). Only then should the base-attacker return to `role=ATK`.
   (With no GO wired, confirm it instead resumes after `PROMOTE_RESUME_MS`.)
5. **Dead-radio check:** unplug one nRF24 and power up that robot alone. It must
   boot and run its static base role normally (`radio=absent`), never hang.

Tick all five off on real hardware before relying on the link in a match.

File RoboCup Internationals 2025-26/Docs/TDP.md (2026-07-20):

## Timestamp

*Tijdstempel*

28-6-2026 15:58:32

## Email Address

*E-mailadres*

kushals@vasantvalley.edu.in

## TDP File

*TDP File Upload (Not required)*

## Team Name

*What is your team's name?*

VVS Ballers

## League

*What league do you participate in?*

IR League

## Country

*Where are you from?*

India

## Contact

*If other teams have questions about your robot, now or in the future, what email address(es) can we publish along with this document for people to reach you?

(You can put in multiple email addresses, like multiple team members, an email for the whole team or both. Feel free to share other ways of communication like Discord handles)*

Team email ID - vvsballers@gmail.com
Kushal Sachdeva - kushal.sach78@gmail.com

## Social Media

*Team Social Media Links (if you have any)*

www.instagram.com/vvs_ballers

## Team Photo

*Upload a photo of your whole team with your mentor and robots

Note: This is not mandatory and will be published along with your TDP if you choose to upload something*

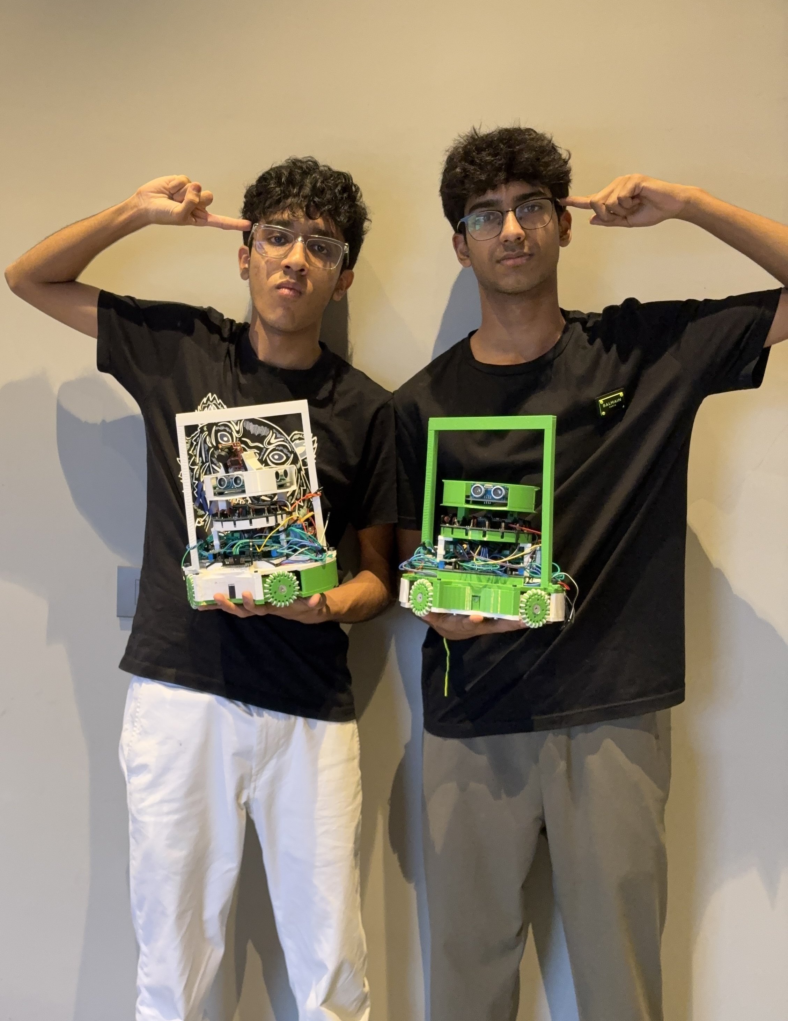
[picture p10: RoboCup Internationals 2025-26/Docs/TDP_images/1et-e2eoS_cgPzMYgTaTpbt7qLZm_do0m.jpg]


## Members & Roles

*What are the names of the team members and their role(s)?*

Kushal Sachdeva (Team Leader) — Electrical, Software & CAD Engineer
Darsh Goel — Mechanical & CAD Engineer

## Meeting Frequency

*How often did your team meet?
(e.g. 90 minutes once per week or a day every weekend.)*

8–10 hours/day from 7–27 June; 4 hours/day from February to May

## Meeting Place

*Where did you meet to work on your robot?
(e.g. a robotics room at school, at some other place, one of your homes, school library etc.)*

A robotics room set up at one of our homes

## Start Date

*When did your team start working on this year's robot?*

February 2026

## Past Competitions

*Which RoboCupJunior competitions have you competed in and in which leagues?*

2023–24 Season
	•	RoboCup Regionals – Best Innovation Award (qualified to Nationals)
	•	RoboCup Nationals – Best Robot Design Award (qualified to Asia-Pacific)

2024–25 Season
	•	RoboCup Regionals – 3rd Place (qualified to Nationals)
	•	RoboCup Nationals – 3rd Place (qualified to Internationals)
	•	RoboCup Internationals, Brazil – Top 20 worldwide

2025-26 Season
	•	RoboCup Regionals – Best Innovation Award (qualified to Nationals)
	•	RoboCup Nationals – 1st Place (qualified to Internationals)

## Mentor Contribution

*Which parts of your work received the most contribution from your mentor?*

External Nano caps motor-driver current (overheating); bulk cap stopped Ultrasonic PCB resets; IR smoothing + camera fixed IR's short range.

## Workload Management

*How did you manage the workload?*

We planned in Notion (every task assigned per member with a deadline), shared all PCB, 3D-design and code files on Google Drive, and ran a WhatsApp group for daily task lists and progress updates.

## AI Tools

*Which AI tools did you use?*

We used Claude's Fusion 360 MCP to help design the supporting beams that hold the IR sensor, and to help lay out the Power PCB and Ultrasonic PCB

## Robot1 Overall

*Robot 1 Overall View*

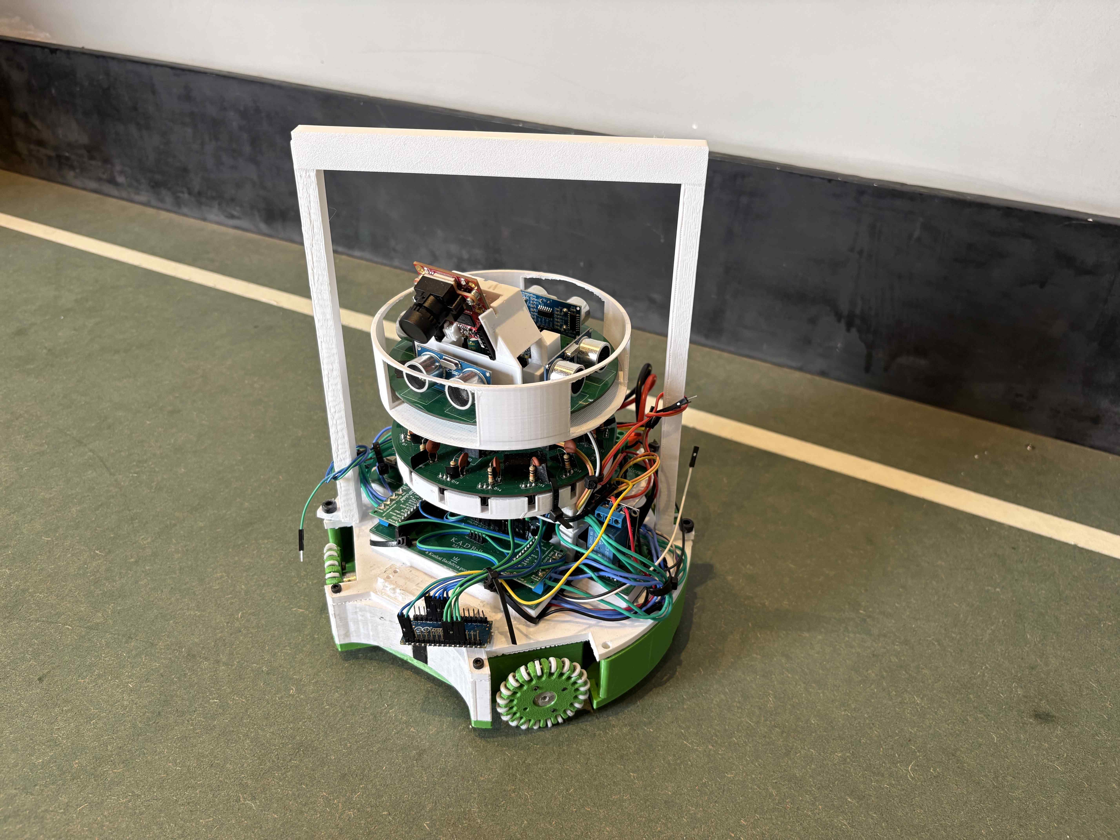
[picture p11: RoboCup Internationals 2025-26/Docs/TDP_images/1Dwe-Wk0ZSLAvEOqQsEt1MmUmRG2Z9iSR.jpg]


## Robot1 Front

*Robot 1 Front view*

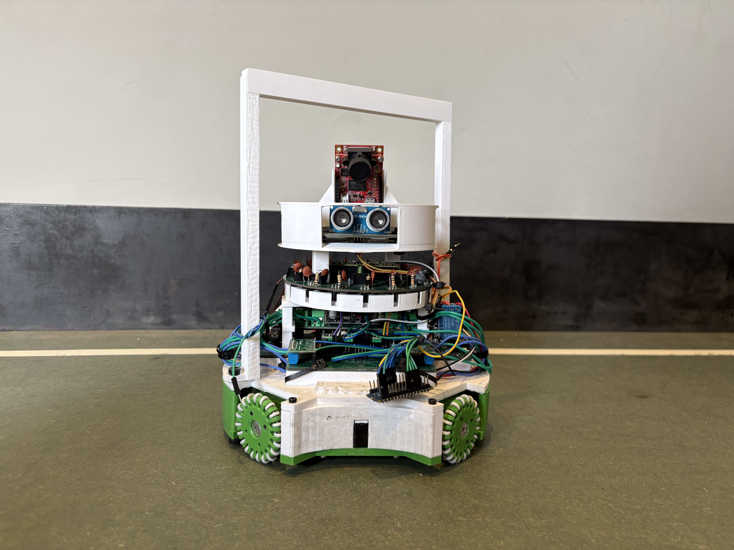
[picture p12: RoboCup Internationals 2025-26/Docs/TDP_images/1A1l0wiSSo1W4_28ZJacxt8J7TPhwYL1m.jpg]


## Robot1 Back

*Robot 1 Back view*

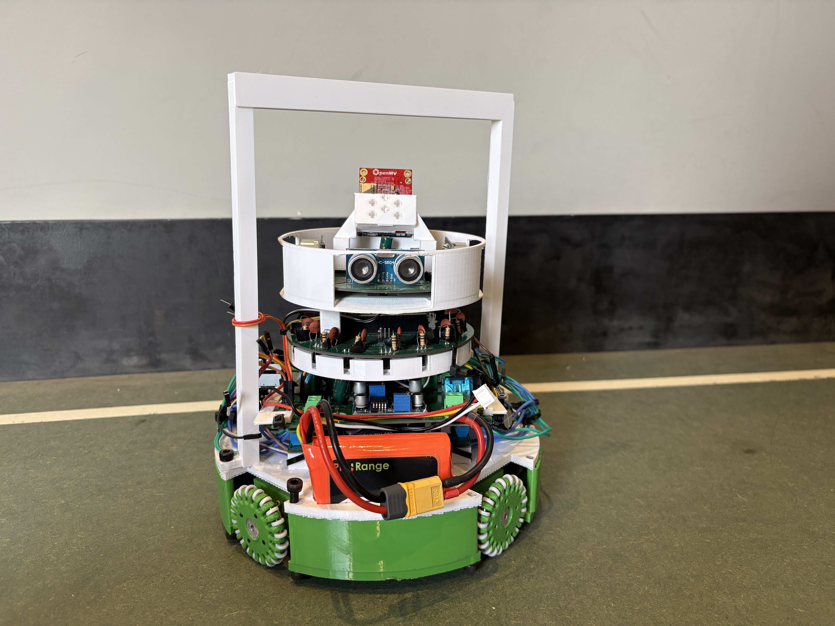
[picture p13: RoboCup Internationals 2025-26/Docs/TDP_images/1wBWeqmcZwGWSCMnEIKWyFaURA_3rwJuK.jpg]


## Robot1 Top

*Robot 1 Top View*

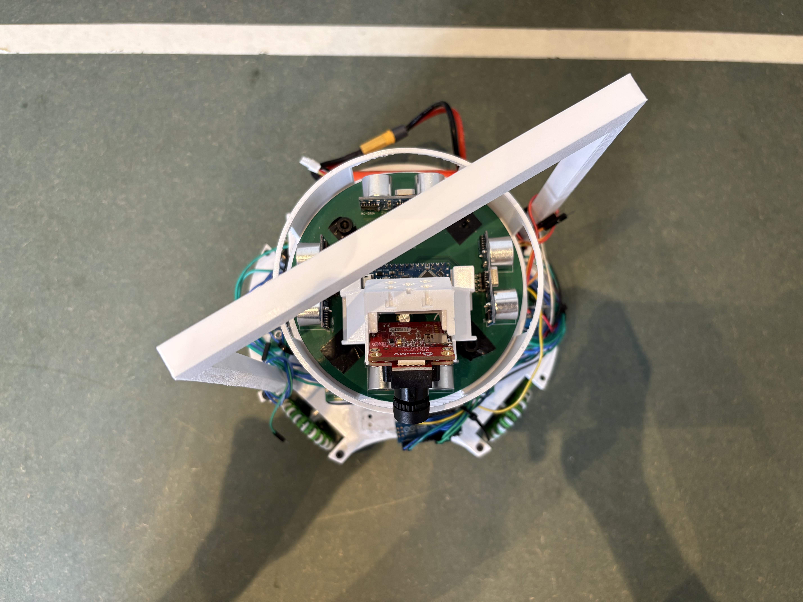
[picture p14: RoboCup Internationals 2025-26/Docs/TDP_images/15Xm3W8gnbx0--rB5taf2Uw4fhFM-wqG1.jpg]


## Robot1 Bottom

*Robot 1 Bottom View*

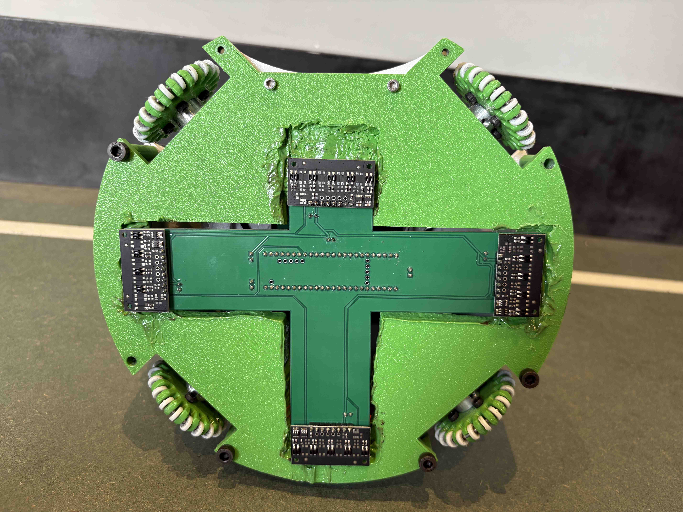
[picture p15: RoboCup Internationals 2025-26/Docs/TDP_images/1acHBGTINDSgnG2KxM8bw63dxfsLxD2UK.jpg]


## Robot1 Right

*Robot 1 Right View*

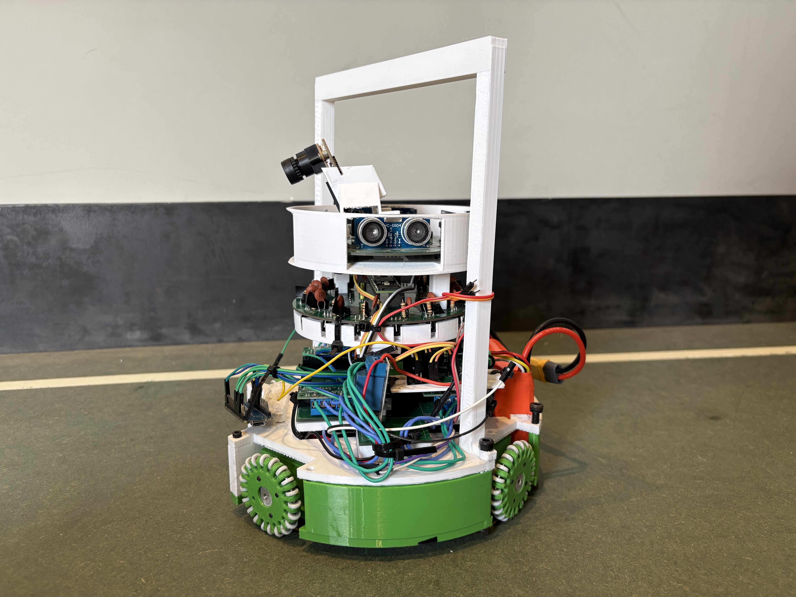
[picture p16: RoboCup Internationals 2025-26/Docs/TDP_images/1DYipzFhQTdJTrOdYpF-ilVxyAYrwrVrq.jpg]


## Robot1 Left

*Robot 1 Left View*

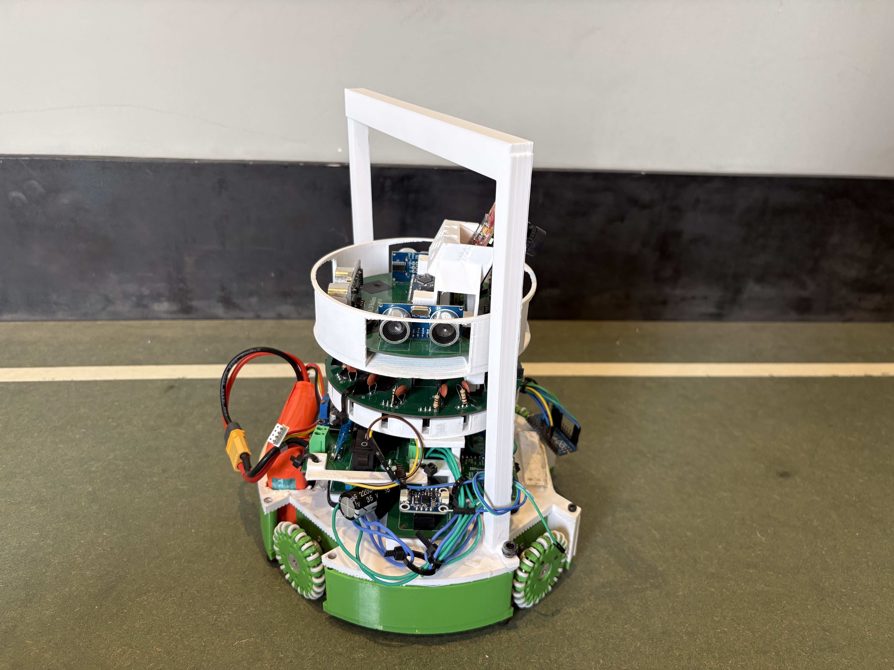
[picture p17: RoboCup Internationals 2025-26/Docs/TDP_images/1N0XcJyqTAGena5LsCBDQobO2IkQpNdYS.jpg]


## Robot2 Overall

*Robot 2 Overall View*

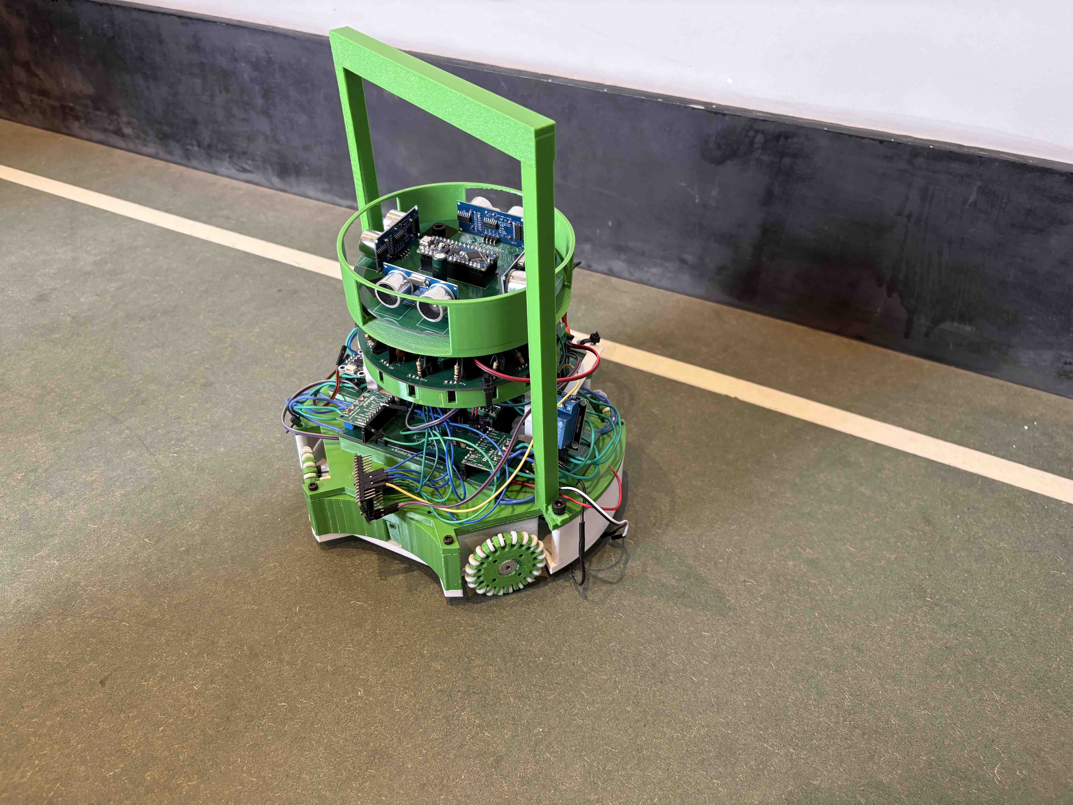
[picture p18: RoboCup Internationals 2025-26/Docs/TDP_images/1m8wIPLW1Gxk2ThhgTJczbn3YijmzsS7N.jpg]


## Robot2 Front

*Robot 2 Front view*

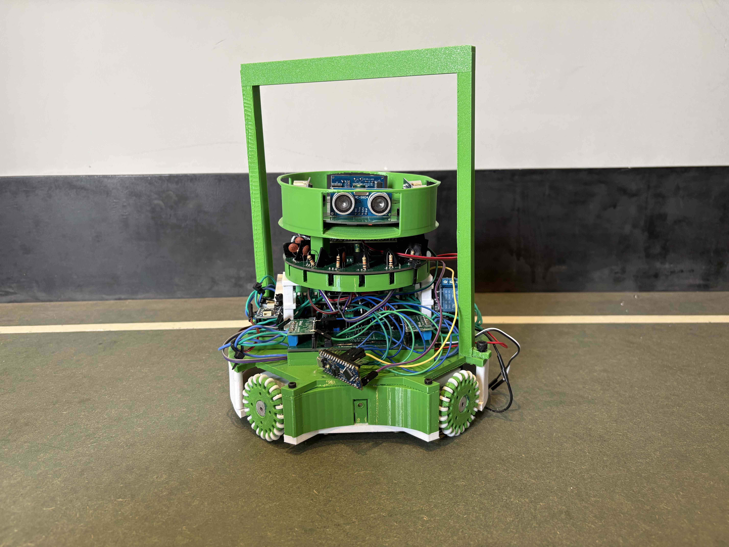
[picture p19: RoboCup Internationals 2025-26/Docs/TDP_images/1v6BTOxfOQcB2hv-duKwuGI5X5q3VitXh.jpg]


## Robot2 Back

*Robot 2 Back view*

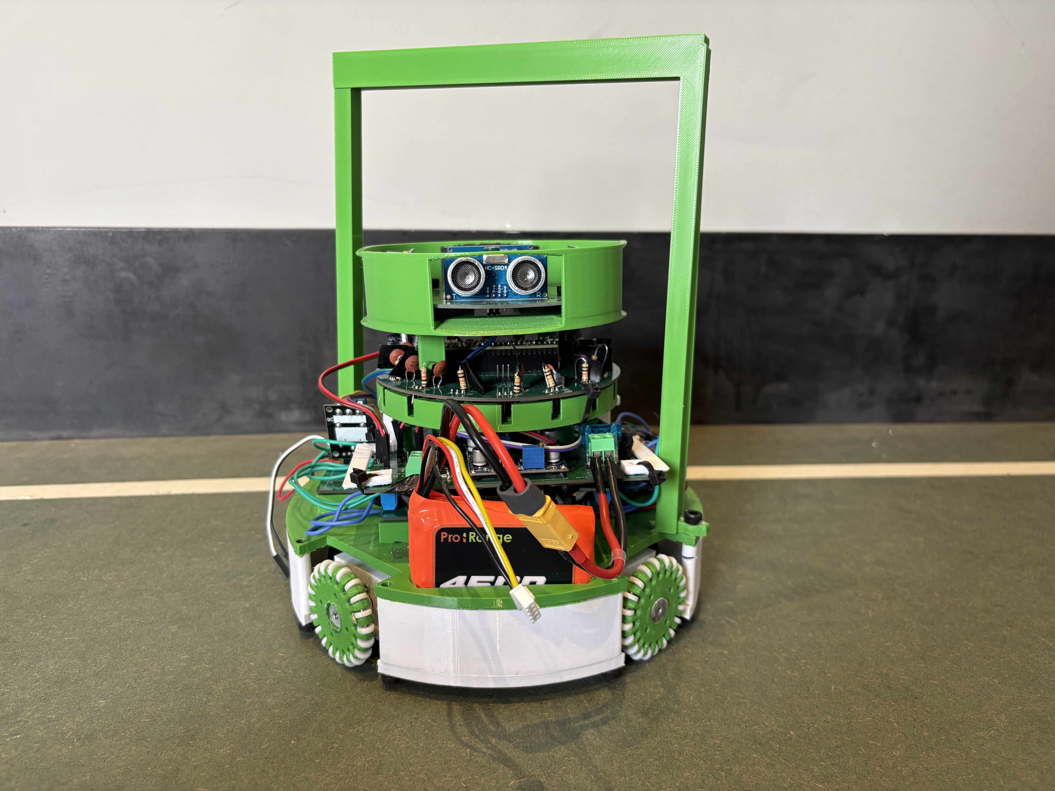
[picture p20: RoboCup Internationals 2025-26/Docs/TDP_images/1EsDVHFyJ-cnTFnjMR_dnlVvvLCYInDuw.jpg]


## Robot2 Top

*Robot 2 Top View*

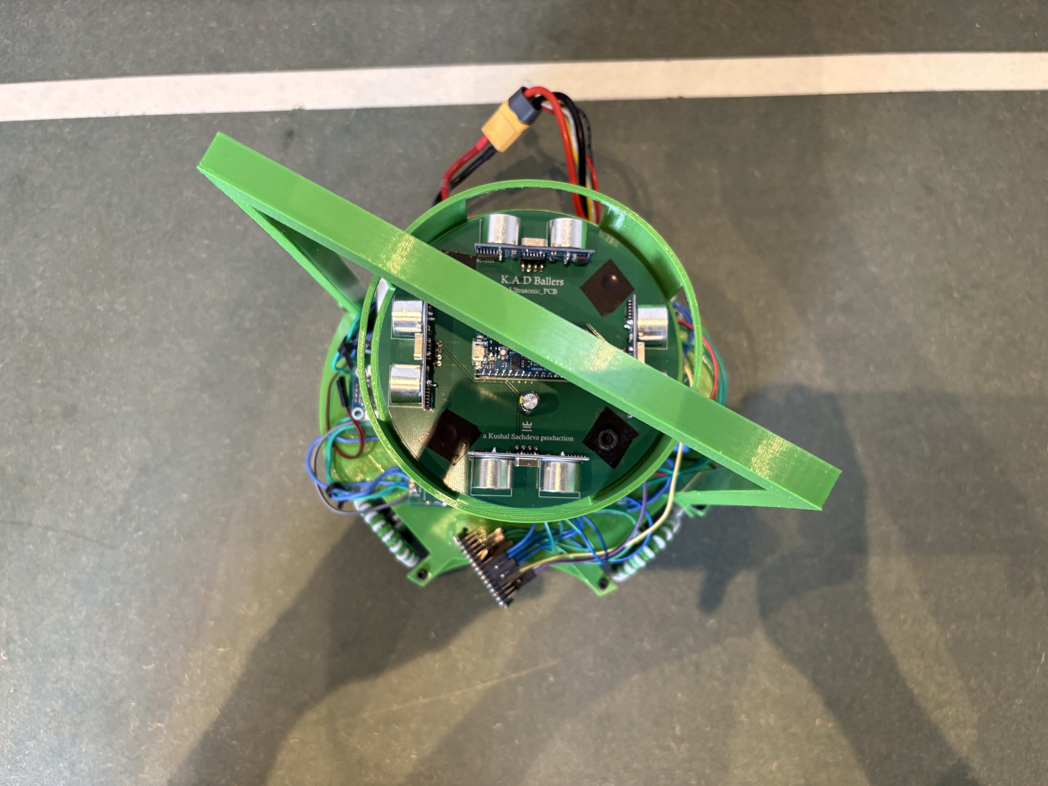
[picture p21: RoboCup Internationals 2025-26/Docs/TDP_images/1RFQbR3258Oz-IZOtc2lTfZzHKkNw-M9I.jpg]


## Robot2 Bottom

*Robot 2 Bottom View*

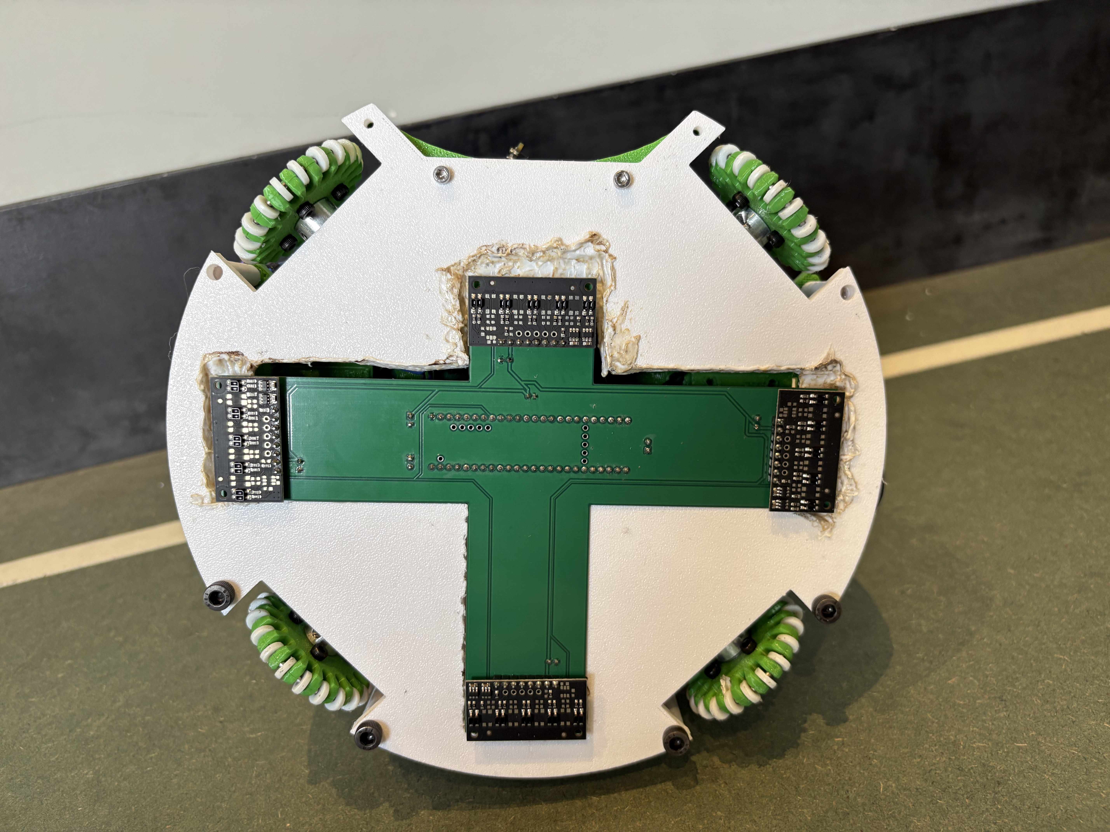
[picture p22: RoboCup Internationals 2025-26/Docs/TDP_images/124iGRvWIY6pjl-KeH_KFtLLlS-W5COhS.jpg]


## Robot2 Right

*Robot 2 Right View*

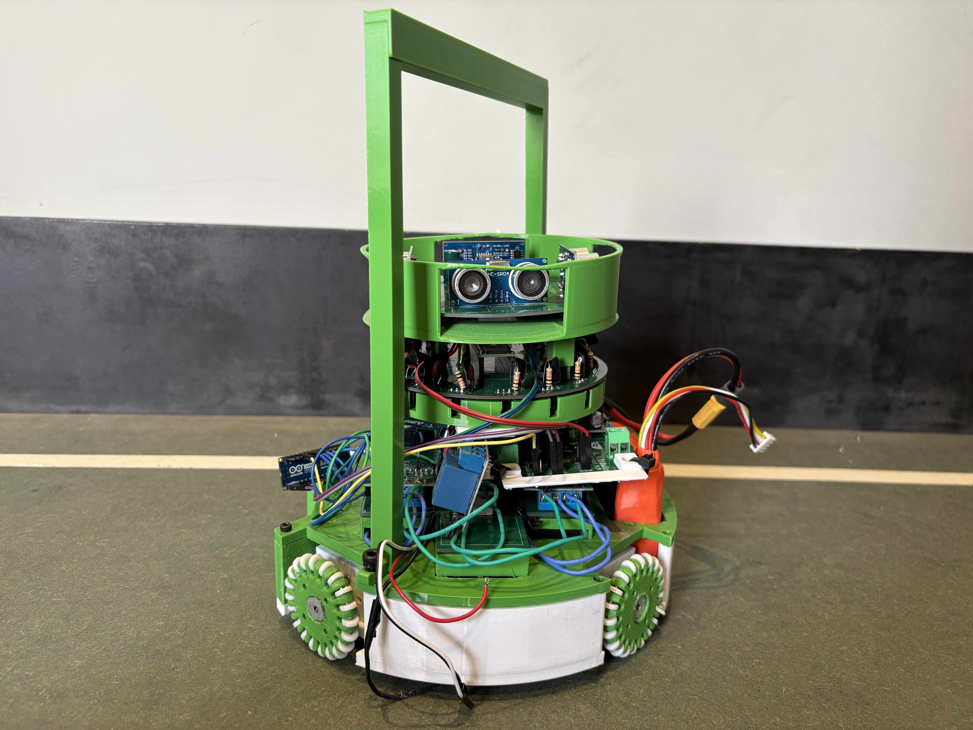
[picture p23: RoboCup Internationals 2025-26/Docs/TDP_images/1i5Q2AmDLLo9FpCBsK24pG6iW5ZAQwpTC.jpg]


## Robot2 Left

*Robot 2 Left View*

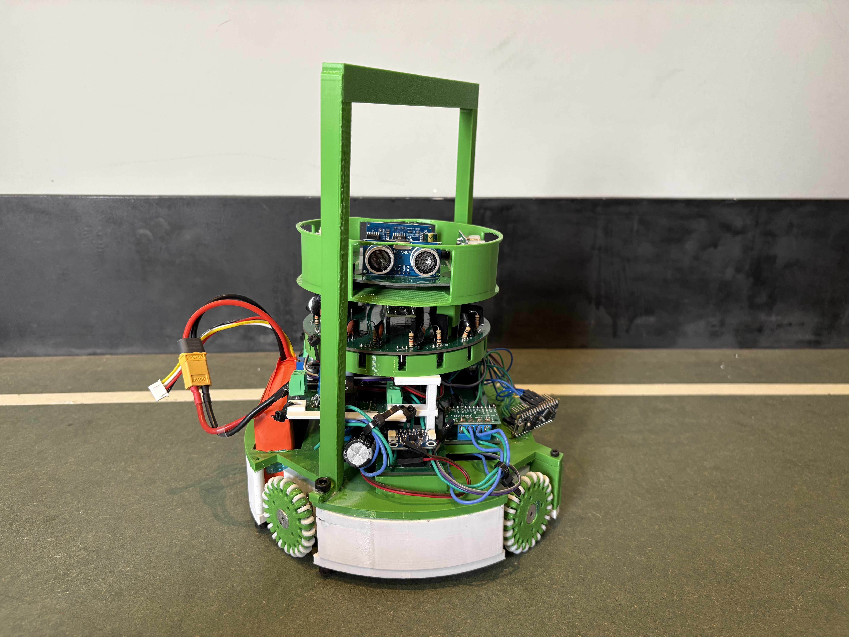
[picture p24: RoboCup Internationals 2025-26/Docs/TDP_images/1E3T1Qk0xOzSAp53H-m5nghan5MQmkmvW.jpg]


## Mechanical Design

*How did you design the mechanical parts of your robots?*

Designed in Fusion 360 from hand sketches. With our physics teacher we compared 3- vs 4-omni-wheel layouts, wheel diameters and sensor placement within the 22 cm / 1.5 kg IR-league limits; the 4-wheel diamond won for holonomic agility and even traction. To improve it we added a 3D-printed support-beam frame that keeps the IR ring rigid and planar, sized the capture mouth to the 1.5 cm ball-zone limit, and packed the five PCBs into a compact stack.

## Build Method

*How did you build your design?*

PCBs were made by JLCPCB; parts were 3D-printed on a Bambu Lab printer in PETG (TPU for grip). We tuned print tolerances, reamed the IR-cover holes to 3.2 mm, and reshaped the support beams to clear the Power-PCB terminals and Teensy USB.

## Motors & Reason

*How many motors have you used and why?*

4 motors, one per omni wheel in a diamond (Pololu 20D mm 12 V gearmotors). Four wheels give true holonomic motion - the robot drives straight at the ball from any bearing while the gyro holds heading - and spread force evenly for pushing duels. We 3D-printed our own omni wheels (PETG hubs + TPU rollers) so the diameter, roller count and grip fit our chassis and the smaller ball.

## Kicker Design

*If your robot has a kicker, explain how you designed and built the mechanics of the kicker*

A solenoid kicker in the capture mouth. The 3D-printed capture area cradles the ball within the 1.5 cm zone; a solenoid plunger strikes the ball forward. A printed mount and coupling align the plunger to the ball centre, and the kick only fires once the capture HC-SR04 confirms the ball is seated.

## Dribbler Design

*If your robot has a dribbler, explain how you designed and built the mechanics of the dribbler.*

N/A

## CAD Files

*CAD design files*

https://github.com/Kushal-Sachdeva78/VVS-Ballers-RoboCup/tree/main/RoboCup%20Internationals%202025-26/CAD

## Mechanical Innovation

*Mechanical Innovation*

Our proudest part is the fully self-designed, 3D-printed omni wheels. No off-the-shelf wheel fit our size limit or the smaller 2026 ball, so we built our own: PETG hubs with TPU-gripped rollers, refined over three print rounds to dial in roller diameter, count, grip and concentricity for smooth, slip-free holonomic motion. 
Second: a printed support-beam structure that ties the Main, IR-cover and ultrasonic boards into one rigid stack so the IR ring stays planar and aligned through collisions.

## Mechanical Photos

*Photos of your mechanical designs highlights*

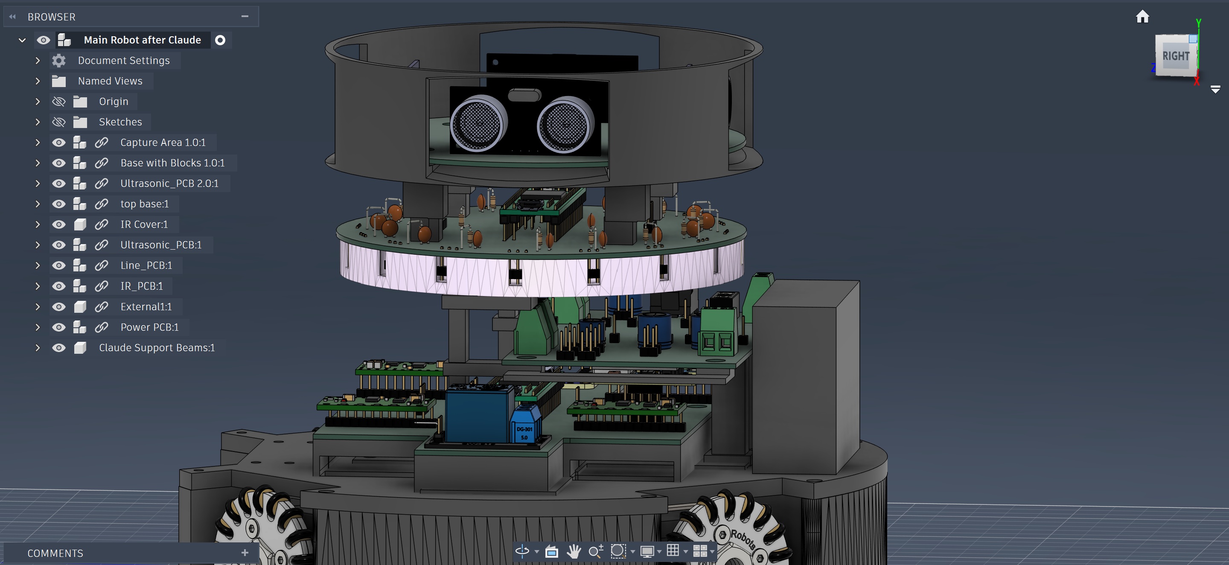
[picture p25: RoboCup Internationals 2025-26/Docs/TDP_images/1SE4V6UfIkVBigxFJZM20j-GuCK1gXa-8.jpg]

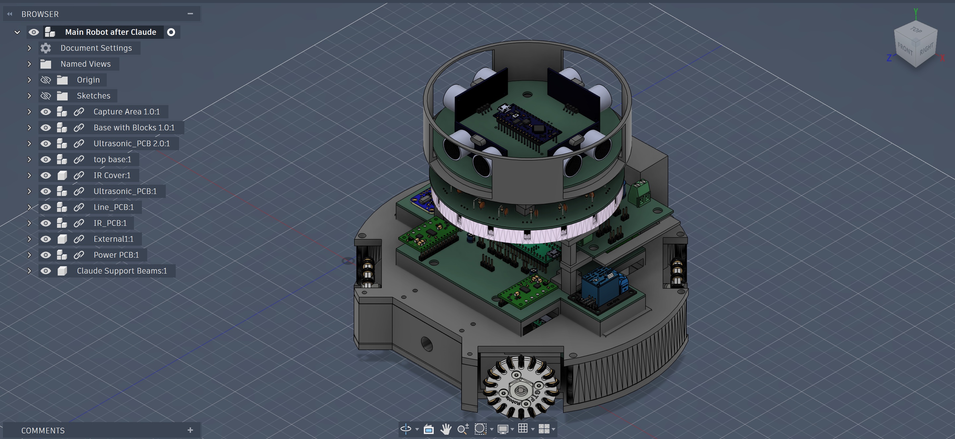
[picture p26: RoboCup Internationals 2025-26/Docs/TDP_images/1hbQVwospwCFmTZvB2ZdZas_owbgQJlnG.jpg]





## Electronics Block Diagram

*Provide us with a block diagram of your robot's electronics*



## Power Circuit

*How does your power circuits work?*

A 12 V LiPo pack feeds a Power PCB which generates: 5 V (buck) for the Teensy boards boards and the OpenMV camera; 3.3 V (buck) for sensor logic; and 48 V (boost) for the solenoid kicker (All this is done on one PCB). The 12 V rail goes directly to the motor drivers. Bulk capacitors sit on each rail

## Motor Drive Circuit

*How do you drive your motors? Explain the circuits you use for that*

Each omni wheel has its own DRV8263H brushed driver (12 V power, 3.3 V logic, PH/EN mode); the Main Teensy feeds each a direction + PWM pin. Each driver's IPROPI current output goes to an Arduino Nano that pulls DRVOFF to coast a motor over ~1 A (stall ~1.6 A), preventing stall overheating.

## Microcontroller & Reason

*What kind of micro controller or board do you use for your robot? Why did you decide to use this part for your robot? If you have more than 1 processor, explain each one separately.*

3× Teensy 4.1:
(1) Main board: chosen for its 600 MHz speed and many hardware UARTs (it must service 5 serial links + the comms module at 100 Hz).
(2) IR ring board: needs to read 16 analog channels fast with on-chip averaging; 
(3) Line ring board: reads 18 analog channels at >500 Hz. 2×

Arduino Nano Every:
(4) Ultrasonic board: Receives values from 4 HC-SR04s; 
(5) Motor-current limiter: Current protection runs independently of the main code. 

Plus the OpenMV H7 as a vision coprocessor.

## Motor Control

*How do you use your processor to move your motors?*

The main Teensy 4.1 PWMs four DRV8263H drivers (one direction pin + one analogWrite PWM pin each, shared SLEEP, 12 V). It mixes a translation pattern with a gyro heading-correction term, so it strafes any direction while facing forward. A separate Nano caps current via IPROPI/DRVOFF.

## Ball Detection

*How does your ball detection sensors and/or camera[s] work?*

A 16-channel TSSP58038 IR receiver ring is the primary ball sensor - the IR-league ball emits IR, and each receiver's reading becomes an intensity (baseline - raw). An OpenMV H7 camera complements it: besides finding the goal, keeper and open-corner aim, it also detects the orange ball, letting us cross-check and reconfirm the IR ring's bearing - camera+IR fusion that helps at short range where the IR ring alone struggled. The camera sends its data to the main board as a 11-byte frame.

## Line Detection

*How does your line detection circuits work?*

A dedicated Line PCB carries four QTR-MD-05A IR-reflectance arrays - 18 sensors facing the floor on all sides. The white field line reflects differently from the green carpet (white reads low), and a board flags 'line' when >=2 of its channels cross threshold. The four ultrasonics range the walls.

## Navigation/Position Sensors

*What sensors do you use for navigation and how are these sensors connected to your processor? What sensors do you use to find your position in the field? What about the direction your robot faces?*

Direction: a BNO055 9-DOF IMU on the main board (I2C/Wire2, address 0x28) in IMUPLUS mode, so the drifting magnetometer is ignored and gyro+accel give a stable heading for the 100 Hz hold-PID. Position: four HC-SR04 ultrasonics, one per side, wired to the ultrasonic Nano that streams their distances to the main board for boundary and goal standoff.

## Kicker Circuit

*How do you drive your kicker system? How does the circuit make the kicker work?*

A relay module (IN1 = pin 22, active-HIGH) switches the 48 V solenoid; a capture HC-SR04 over the mouth (TRIG 20 / ECHO 21) confirms the ball before firing. Firmware safety: 2-sample capture debounce, a fixed 500 ms pulse, 1.5 s cooldown, a hard 600 ms max-on cutoff, and a boot-safe relay state.

## Dribbler Circuit

*How does your dribbler system work? What components and circuits did you use to drive it?*

N/A

## Schematics

*Schematics of your robot*







## PCB

*PCB of your robot*







## Electronics Innovation

*Electronics Innovations*

Our federated multi-PCB architecture: three purpose-built boards talk over CRC-8-framed UART, so a glitch on any wire is rejected, not acted on. We are proudest of three boards. The Power PCB is compact yet generates and distributes four rails (12 V, 5 V, 3.3 V, 48 V) cleanly and continuously across the whole robot from one battery. The IR PCB gives each of its 16 receivers its own RC filter, smoothing the pulsed IR into a clean analog level the Teensy reads as a precise bearing. The Main PCB integrates everything on one board - it takes data from every sensor link, runs the heading PID, drives all four motors, and carries the BNO055 IMU and the solenoid kicker at once.

## Circuit Photos

*Photo of your circuit boards highlights*







## Ball Detection Method

*How do you find where the ball is? How do you read the data from the ball detection sensors and/or camera?*

The IR board reads all 16 channels, converts each to intensity = baseline - raw, rejects ambient and damps lone spikes. It then takes an intensity-weighted vector sum (atan2 over all lit sensors) for a smooth bearing, with hysteresis (60/35) and EWMA smoothing, and sends <dir>a<dist>b (500 = no ball) to the main board. The camera is read as an 11-byte frame; stale links (>200 ms) are ignored.

## Ball Catch Algorithm

*How does your algorithm work to catch the ball? Is there a difference between your robots in how they move towards the ball? Explain the differences.*

Attacker: it sorts the IR bearing into a drive sector and translates straight at the ball (speed 250) while the gyro holds heading; on capture it switches to aim-and-kick. 

Defender: it does not chase up-field - it stays on its goal line and runs a lateral PID on the ball's bearing to keep its body between ball and goal, with an intercept boost when the bearing moves fast, clearing on contact.

## Positioning Algorithm

*How do you use your sensors in your algorithm to find your position inside the field and how do you use that position to move your robots around?*

The four ultrasonics are used reactively (no x/y estimate), each giving its wall distance. The attacker uses them with the line ring to flee field edges; the defender centres in the mouth from the left/right difference and holds a set distance-range from its own goal via the back sensor. Drive is holonomic: a translation vector plus the heading-PID correction, normalised so no wheel saturates.

## Line Algorithm

*How does your robot find the lines to stay inside the field? What algorithms do you use to avoid going out of bounds?*

Walls are sensed by ultrasonics, the white boundary by four QTR-MD-05A reflectance arrays (>=2 white channels = line). Attacker: a side is the edge only when its ultrasonic reads <300 mm AND that side sees white, debounced 3 passes; it then flees, never on a stale link. This two-of-two rule stops a false reading triggering an out-of-bounds penalty. Defender: the line keeps it on the goal edge.

## Goal Algorithm

*What algorithms do you use to score goals? How do you use your kicker and dribbler to handle the ball?*

The camera finds the goal and keeper and returns the open-corner bearing. On capture (mouth HC-SR04 <45 mm, 2 samples) the attacker holds heading, then spins in place until the open corner is within 5 deg ahead, and only then fires the 48 V solenoid (500 ms pulse, 1.5 s cooldown, 600 ms hard cutoff). The defender uses the same kicker for a short clearing kick. No dribbler.

## Defense Algorithm

*What algorithms do you use to avoid the opponent team scoring? How do your robots defend your own goal?*

The defender's Defender_Full runs GUARD (centre on the line, hold standoff) → TRACK (lateral-PID onto the ball, intercept boost) → CLEAR (push/kick the ball away on contact) → RECOVER (re-home to the line). A back-wall safety rule forbids reversing toward its own goal when the rear wall is < 90 mm, so a bad reading can't drive it into its own net.

## Robot Communication

*Do your robots communicate with each other? How do you use this communication to your advantage?*

Yes - the robots share status over a 2.4 GHz link (the only band RCJ permits for inter-robot comms). We use it for automatic role-switching: if one robot drops off the link (fouled, penalised or removed), its partner switches from attacker to defender so our goal is never left open while we are a robot down; they resume normal roles when it returns at kick-off.

## Software Innovation

*Software Innovations*

Both are about clean data from cheap sensors.

(1) Ultrasonic smoothing: we ping opposite sensors together to kill cross-talk, temperature-compensate distance, run a per-sensor median-of-3, and coast over dropouts so a missed echo never blinks a wall away.

(2) IR tracking: instead of strongest-sensor, we sum intensity-weighted vectors over all lit receivers (atan2) with hysteresis and spike damping, for a smooth bearing on the small fast ball. Both feed our fused line+ultrasonic boundary escape

## GitHub Link

*GitHub link*

https://github.com/Kushal-Sachdeva78/VVS-Ballers-RoboCup/tree/main/RoboCup%20Internationals%202025-26/Firmware

## BOM

*Bill of Materials (BOM)*

[https://drive.google.com/open?id=1EPaQ7X6d3vpanGlAbN6bnXVHUaxpJ8NOUNK7xiksze4](https://drive.google.com/open?id=1EPaQ7X6d3vpanGlAbN6bnXVHUaxpJ8NOUNK7xiksze4)

## Cost

*How much did it cost you to build your robots?*

Robots (cost of components that are in your robots right now): 600 Euro each
Experiments (failed builds, broken hardware etc.): 1200 Euro
Spare Parts (spare motor drivers, sensors, fuses, PCBs, etc.): 1000 Euro
Environment (fields, balls, 3D printer, soldering station, power tools, etc.) : 1100 Euro

## Funding

*How did you gathered the funds to build the robots?*

50% Sponsors 
0% School
50% Parents

## Affordability

*How affordable was it to compete in RoboCupJunior Soccer?*

4

## Answer Check

*Have you checked all of your answers?*

Yes!

## Publication Consent

*We publish TDPs and posters during or after the competition as described in the beginning*

Yes, we acknowledge everything submitted in the above form can be published.

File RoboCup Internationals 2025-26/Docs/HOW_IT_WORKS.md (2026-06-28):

# How the Robot Works

A full technical walkthrough of the VVS Ballers RoboCupJunior Soccer robots — the
electronics, the firmware on each board, how the boards talk to each other, and the
behaviours that let the robot chase, aim, shoot, and stay in bounds. Everything here
is drawn from the firmware in [`Firmware/`](../Firmware) and the wiring in
[`PCB/Wiring/`](../PCB/Wiring).

> The **attacker** and **defender** are the same robot with different main-board
> firmware. Sections below cover the shared hardware first, then the two roles.

---

## 1. System architecture

The robot is a **federation of microcontrollers**, not one big program. Each fast
sensor job runs on its own MCU and streams a compact result to the **main board**,
which fuses everything and drives the wheels and kicker.

```
            IR ring (Teensy 4.1)            OpenMV H7 camera
            16× TSSP58038                   goal / keeper vision
                 │ Serial (ASCII)                │ Serial2 (9-byte)
                 ▼                                ▼
   Line ring ─Serial8(9-byte)►  ┌─────────────────────────┐  ◄Serial3(13-byte)─ Ultrasonic
   4× QTR-MD-05A                 │   MAIN BOARD Teensy 4.1  │                     4× HC-SR04
   (Teensy 4.1)                  │  • BNO055 heading PID    │                     (Nano Every)
                                 │  • behaviour state mach. │
   Comms module ─Serial7/GO-STOP►│  • 4× DRV8263H omni drive│
   (referee start/stop)          │  • capture sensor + kick │
                                 └─────────────────────────┘
                                        │            │
                                  4 omni wheels   48 V solenoid kicker
```

Why split it up: the IR ring, the line ring, and the ultrasonics each need to be
sampled fast and continuously. Giving each its own MCU keeps those tight loops off
the main control CPU, and the **CRC-8-checked binary links** (ultrasonic, line, camera) mean a glitch on those wires
is rejected rather than acted on.

| Board | MCU | Link to main | Source |
|---|---|---|---|
| IR ball ring | Teensy 4.1 | Serial4 (ASCII) | [`Firmware/IR_Ball_Sensor`](../Firmware/IR_Ball_Sensor) |
| Line ring | Teensy 4.1 | Serial8 (binary) | [`Firmware/Line_Sensor`](../Firmware/Line_Sensor) |
| Ultrasonic | Nano Every | Serial3 (binary) | [`Firmware/Ultrasonic`](../Firmware/Ultrasonic) |
| Camera | OpenMV H7 | Serial2 (binary) | [`Firmware/Camera`](../Firmware/Camera) |
| Comms module | (referee) | Serial7 + GO/STOP pins | rules module |
| Motor-current (optional) | Nano Every | — (external DRVOFF) | [`Firmware/Motor_Current`](../Firmware/Motor_Current) |

---

### Block diagram & parts list

A wiring-level block diagram of the whole electronics stack:

VVS Ballers electronics block diagram

The complete bill of materials (every board, sensor, driver, and the kicker) is in
[`VVS_Ballers_BOM.xlsx`](VVS_Ballers_BOM.xlsx).

---

## 2. Power and electrical

From [`PCB/Wiring/Power_PCB.pdf`](../PCB/Wiring/Power_PCB.pdf) and
[`PCB/Wiring/Main_PCB.pdf`](../PCB/Wiring/Main_PCB.pdf):

- **Battery → fuse → main switch → switched 12 V node.** Best-practice single-pole
  switching on the positive lead; ground stays common.
- The switched 12 V feeds four converters and the battery-capacity indicator:
  - **12 V rail** → main board (motor supply); bulk cap 1000–2200 µF for motor noise.
  - **5 V buck** → main, IR, line, ultrasonic boards **and the OpenMV camera**.
  - **3.3 V buck** → main, IR, line boards (sensor logic).
  - **48 V boost** → the solenoid kicker supply (bulk cap ≥ 63 V).

The **48 V** solenoid rail sits exactly at the rules' power ceiling (≤ 48 V DC) — the
hardest legal kick. Logic and motors stay on the lower rails.

On the main board the Teensy 4.1 takes 5 V on VIN; the BNO055, capture HC-SR04 and
sensor logic run at 3.3 V; the four motor drivers take 12 V power and 3.3 V logic.

---

## 3. Drive base — omni wheels, drivers, heading hold

### Motors and pin map

Four omni wheels in a diamond, each on a **DRV8263H** brushed driver in PH/EN mode
(`MODE/SR → GND`, `DRVOFF → Nano D2-D5`, `SLEEP → pin 6` shared). Motors are Pololu 12 V gearmotors.

| Motor | IN1 / IN2 (Teensy) | In firmware |
|---|---|---|
| M1 | 2 / 3 | `M1_EN=2, M1_DIR=3` |
| M2 | 4 / 5 | `M2_EN=4, M2_DIR=5` |
| M3 | 9 / 10 | `M3_EN=10, M3_DIR=9` |
| M4 | 11 / 12 | `M4_EN=12, M4_DIR=11` |

`setMotor()` drives one pin as direction and PWMs the other (`analogWrite`, speed
clamped to ±255). The optional **IPROPI** current-sense and **FAULT** outputs are
broken out but unused in the default build.

### Translation without rotation

The robot drives in straight "sectors" while a gyro keeps it pointing forward. Two
sign tables do the mixing:

- `moveSign[sector][motor]` — the four wheel signs for FORWARD / RIGHT / LEFT / BACK.
- `turnSign[4] = {-1, +1, -1, +1}` — the spin-in-place mix.

`driveSector(sector, speed, correction)` = `moveSign·speed + turnSign·correction`.
With `speed = 0` only the `turnSign·correction` term survives, which is a **pure spin
in place** — exactly how the attacker rotates to aim. Both drives **normalise** their
four wheel commands — if any would exceed 255, all four are scaled by 255/max, so the
heading and translation direction are preserved at full tilt rather than distorted by
per-wheel clamping. The defender additionally uses a fuller holonomic mixer,
`driveXY(vx, vy, corr)`, combining a forward and a sideways velocity.

### Heading-hold PID (BNO055)

A **BNO055** IMU on `Wire2` (SDA 25, SCL 24, address 0x28) runs in **IMUPLUS** mode
— gyro + accelerometer fusion, magnetometer ignored, so nearby motors and steel
can't pull the heading. At boot the firmware averages 20 yaw samples to define
"forward", then a PID holds it:

```
Kp = 6.0,  Ki = 0.0,  Kd = 0.5,  MAX_CORRECTION = 200,  loop = 100 Hz
correction = K_SIGN · (Kp·err + Ki·∫err + Kd·dErr),  err = wrap180(heading − setpoint)
```

`K_SIGN` flips the correction sense per chassis wiring (−1 on the attacker). Because
IMUPLUS yaw drifts slowly, the defender adds a **heading dead-band** (ignore errors
< 3°) and **relaxes heading when parked**, so it doesn't slowly spin chasing drift.

---

## 4. Sensors

### 4.1 IR ball ring — where is the ball?

**Hardware** ([`PCB/Wiring/IR_PCB.pdf`](../PCB/Wiring/IR_PCB.pdf)): 16× **TSSP58038**
IR receivers in a ring on a dedicated Teensy 4.1, analog channels **A0–A15**, with
**front = channel 15**, 22.5° apart (360/16). Each channel is an RC low-pass —
`IRout → 10 kΩ → pin, pin → 0.22 µF → GND` — whose time constant
(10 k × 0.22 µF = 2.2 ms ≈ 72 Hz) sets the real ceiling on how fast a moving ball can
be tracked.

**Algorithm** ([`Firmware/IR_Ball_Sensor/Code2_Calibrated`](../Firmware/IR_Ball_Sensor)):

1. Read all 16 channels. Convert each to an **intensity = baseline − raw** (the
   sensors pull *down* with IR, so a lower raw means a stronger signal). Anything at
   or below `NOISE_FLOOR = 12` is treated as ambient and zeroed.
2. Damp a **lone hot channel** whose both neighbours are dark (a reflection/noise
   spike) — a real ball always lights ≥ 2 adjacent sensors.
3. Take the **intensity-weighted vector sum** over every lit channel and
   `atan2(Σw·sinθ, Σw·cosθ)` → the ball **bearing**. Summing vectors is smooth across
   the 0°/360° wrap and more robust than "strongest sensor ± 2".
4. **Detection hysteresis:** assert "ball seen" when the peak intensity ≥ 60, release
   below 35 — no chattering at the edge of range.
5. Smooth the bearing with an EWMA (α = 0.45).

**Calibration** (baked into `Code2_Calibrated`, captured 2026-06-27): per-channel
no-ball baselines (≈ 1006–1007, just under the 10-bit rail) and per-channel gains
(all within ±4 % of 1.0 — the ring is well matched, so gain is not the limiting
factor). `Code2_Refined` is the same code with default (uncalibrated) values for
reference, and `Calibration.ino` is the bench tool that captures baselines and
streams all 16 channels to the Serial Plotter.

**Output to main** (IR board Serial2 → main Serial4): legacy ASCII frame
`"<dir>a\t\r\n<dist>b\t\r\n"`, with `500` as the no-ball sentinel. The main board
parses `a` as end-of-direction and `b` as end-of-frame, and treats the bearing in a
**reversed** convention (a ball *ahead* reads near ±180°) — see §6.

### 4.2 Ultrasonic ring — where are the walls?

**Hardware** ([`PCB/Wiring/`](../PCB/Wiring) + [`Firmware/Ultrasonic`](../Firmware/Ultrasonic)):
an **Arduino Nano Every** with **4× HC-SR04**, one per side:

| Side | Sensor | TRIG / ECHO |
|---|---|---|
| FRONT | U4 | D8 / D9 |
| RIGHT | U3 | D4 / D5 |
| BACK | U2 | D6 / D7 |
| LEFT | U1 | D2 / D3 |

**Opposite-pair pinging** is the key trick: firing all four at once lets an adjacent
sensor hear another's burst (false short reading); firing one at a time is safe but
slow. So the board fires **FRONT + BACK together, then RIGHT + LEFT together** — two
adjacent sensors never sound at the same instant, and the cycle is halved. Distance
uses a **temperature-compensated speed of sound** (`c = 331.4 + 0.6·T`), a per-sensor
**median-of-3** kills single fliers, and on a missed echo the sensor **coasts** on
its last value for 2 cycles before reporting out-of-range. Full set runs at ~50 Hz;
range clamps to 20–2600 mm (the field's long axis is 243 cm). A ~1 s watchdog resets
the board if `loop()` ever stalls.

`Ultrasonic_Receiver_MainBoard.ino` is the drop-in parser the main firmware reuses.

> **Orientation note:** the board's natural index order is clockwise F, R, B, L, but
> on this robot it's mounted rotated 180°, so the main firmware remaps the enum to
> `{US_BACK=0, US_LEFT=1, US_FRONT=2, US_RIGHT=3}`. If the board is ever re-seated,
> that enum is the one place to fix. Because the ultrasonic board is **5 V** and the
> Teensy RX is **3.3 V-only**, its TX must be level-shifted into the main board.

### 4.3 Line ring — where is the boundary?

**Hardware** ([`PCB/Wiring/Line_PCB.pdf`](../PCB/Wiring/Line_PCB.pdf)): a Teensy 4.1
with **4× QTR-MD-05A** reflectance arrays = **18 channels** (QTR1–3 give 5 each,
QTR4 gives 3). All emitters share **CTRL_ODD → D6**. The four boards face the four
directions in a "plus":

| Board | Direction | Channels |
|---|---|---|
| QTR1 | RIGHT | A0–A4 |
| QTR2 | FRONT | A5–A9 |
| QTR3 | LEFT | A10–A14 |
| QTR4 | BACK | A15–A17 |

On the field surface, the **white line reads *lower*** than the green field (raw
< ~180). A board "sees the line" when **≥ 2** of its channels are white. Three
sketches share the exact pin map:

- **`Line_PCB_Raw_Reader`** — streams raw ADC for every channel; the calibration tool.
- **`Line_PCB_Detect`** — per-channel fixed thresholds (~200) with hysteresis, 500 Hz.
- **`Line_PCB_Baseline`** — learns each channel's green level for 1 s at boot, then
  flags white on a drop of ≥ 5 below that baseline, 1 kHz. No per-sensor tuning; this
  is the easiest to deploy on a new field.

Both detectors emit the **identical 9-byte packet** (§5.3), so the main board decodes
either with no change.

### 4.4 Camera — where is the goal?

**Hardware/firmware** ([`Firmware/Camera/Goal_Cam.py`](../Firmware/Camera/Goal_Cam.py)):
an **OpenMV H7**, forward-facing, no mirror. It does the one job no other sensor can:
**find the goal and the keeper.** Settings are locked (RGB565 QVGA, fixed
exposure/gain/white-balance) so colour thresholds stay stable across a match.

Each frame it finds the largest **yellow** or **blue** goal blob (LAB thresholds) and
the largest **dark** blob overlapping it (the keeper), then computes:

- `attackBearing` — `(cx − centre) · HFOV/width`, + = goal to the robot's right.
- `openCornerBear` — **the aim angle.** If a keeper is present, it splits the goal at
  the keeper and aims the centre of the **larger open slice**; with no keeper it aims
  the **far corner**, inset slightly so the ball still goes in.
- `attackDist` (coarse, focal-length method), `keeperBearing`, `ownGoalBearing`.

**Camera + IR ball fusion.** Both `Goal_Cam.py` and `Goal_Cam_Ball.py` also detect the
orange ball and put its bearing + coarse distance in the frame (flags bit3 +
`ballBearing` + `ballDist`, §5.2). The **IR ring stays the primary ball sensor**; the
main board treats the camera ball as a **short-range cross-check and fallback** — if
the IR ring loses the ball the attacker chases the camera ball, and within
`CAM_BALL_NEAR_CM` (~25 cm) a large camera-vs-IR disagreement makes it trust the camera
bearing (`USE_CAM_BALL_FUSION`; attacker `camPoll` + fusion block). `Goal_Cam_Ball.py`
adds a richer ball overlay for tuning. Save the chosen script to the H7 as `main.py`.

> **Wiring note:** the IR PCB exposes a camera header on pins 34/35 from an earlier
> plan, but the **current firmware reads the camera on the main board's Serial2**
> (RX2 = pin 7), which is what the attacker sketch decodes.

### 4.5 Capture sensor — is the ball in the mouth?

A fifth **HC-SR04** on the main board looks into the dribbler/capture mouth
(TRIG = 20, ECHO = 21). When the ball sits in the mouth it reads `< 45 mm`; after 2
consecutive in-range pings the ball is "captured" and the kicker can arm (§6, §7).

---

## 5. Inter-board communication

Three of the four links are short **binary frames** that share one design: a 2-byte
sync header, a little-endian payload, an integrity byte, and a stale timeout, with the
sync bytes differing between links so a mis-wire can't false-lock one stream onto
another. The **ultrasonic, line, and camera** links all carry an identical **CRC-8
(polynomial 0x07, init 0x00)**, so the main board rejects any corrupted frame. A
per-link **stale timeout (~200 ms)** means frozen or dead data is never acted on. The
**IR** link (§5.4) is the exception — plain delimited ASCII with no checksum.

### 5.1 Ultrasonic → Main (Serial3, 13 bytes)

```
[0]=0xAA [1]=0x55 | F.lo F.hi R.lo R.hi B.lo B.hi L.lo L.hi | status | seq | crc8
  distances: uint16 mm, little-endian
  status:    2 bits/sensor (0=OK, 1=out-of-range, 2=held/coasting)
  crc8:      over payload bytes [2..11]
```

### 5.2 Camera → Main (Serial2, 11 bytes)

```
[0]=0xAA [1]=0x55 [2]=flags [3]=attackBearing(i8) [4]=attackDist(u8)
[5]=openCornerBear(i8) [6]=keeperBearing(i8) [7]=ownGoalBearing(i8)
[8]=ballBearing(i8) [9]=ballDist(u8) [10]=crc8
  flags: bit0 attackGoalSeen, bit1 ownGoalSeen, bit2 keeperSeen, bit3 ballSeen
  crc8: CRC-8 (poly 0x07, init 0x00) over bytes 2..9
```

### 5.3 Line → Main (Serial8, 9 bytes)

```
[0]=0xA5 [1]=0x5A [2]=mask [3..6]=count[0..3] [7]=seq [8]=crc8(over [2..7])
  mask bits: bit0 RIGHT, bit1 FRONT, bit2 LEFT, bit3 BACK
  count[i]: number of white channels on that board (diagnostics)
```

The `0xA5/0x5A` sync is deliberately different from the ultrasonic link's
`0xAA/0x55`.

### 5.4 IR → Main (Serial4, ASCII)

`"<dir>a\t\r\n<dist>b\t\r\n"`; `a` ends the direction field, `b` ends the frame, and
`500` means "no ball". This link is **delimited ASCII with no checksum** — the `a`/`b`
delimiters and the `500` sentinel are the only framing. The distance field is parsed
for sync but ignored.

> **Both robots now decode the same line frame.** `Defender_Full` was previously
> written against a *planned* 8-byte depth/side frame the line boards never emitted; it
> now decodes the **same 9-byte mask/counts frame** above. The keeper uses the FRONT
> flag as the up-field box-edge limit and the RIGHT/LEFT flags as corner limits, with
> the **back ultrasonic** providing the continuous standoff (a reflectance ring has no
> continuous distance). The attacker's fused boundary escape uses the same frame.

---

## 6. Attacker behaviour

`Firmware/Attacker/Attacker_Chase_Aim_Kick_Line` runs a 100 Hz loop with a strict
priority each pass:

```
1. HAVE BALL  → AIM the open corner → KICK     (overrides everything)
2. BOUNDARY ESCAPE (line + ultrasonic agree, debounced)
3. CHASE the ball
4. IDLE
```

**Chase.** The ball bearing from the IR ring is classified into a drive sector —
forward when `|dir| ≥ 150` (the ball reads near ±180 when ahead, by this robot's
reversed convention), right/left in the side wedges, back around 0 — and the robot
translates that way at speed 250 while the heading PID keeps it square.

**Boundary escape (the out-of-bounds defence).** A side counts as the **field
boundary only when both sensors agree**: that side's ultrasonic reads `< 300 mm`
**and** that direction's QTR board sees the white line. The robot then flees the
**closest** confirmed boundary (front→back, right→left, etc.). If *either* the line
or ultrasonic link is stale, no escape fires — the robot never acts on data it can't
trust. A side must also persist for **3 consecutive passes** (`AVOID_CONFIRM`) before
the robot flees, so a single spurious frame can't make it dart out of bounds. This
two-of-two design is deliberate: an out-of-bounds penalty removes the robot for a
full minute and voids any goal scored meanwhile, so a **false** boundary trigger
(needlessly fleeing) and a **missed** one (crossing the line) are both expensive, and
requiring agreement guards against both.

**Aim — "the turn thing".** The moment the ball is captured the robot freezes its
heading, then when the camera reports the goal it sets
`aimHeading = heading + AIM_TURN_SIGN · openCornerBear` and **spins in place** (drive
speed 0, only the heading PID turning the chassis) until the open corner is within
**5°** dead ahead. Only then does it kick. If the goal leaves frame, `aimHeading` is
left untouched, so the robot holds its last good aim on the gyro.

**Kick.** Once captured *and* aimed, a non-blocking state machine fires the solenoid:
`K_IDLE → K_KICKING (500 ms) → K_COOLDOWN (1500 ms)`. Several safety layers wrap it
(see §7).

`REQUIRE_GOAL_TO_KICK` can be set to 0 for bench testing (kick on capture alone, no
camera); the default match build requires the goal to be seen and aligned.

---

## 7. Defender (goalkeeper) behaviour

`Firmware/Defender/Defender_Full` is a five-state machine:
`GUARD → TRACK → CLEAR → RECOVER` (plus `STOPPED` for the referee).

- **GUARD** — centre in the mouth (ultrasonic left/right difference) and hold the
  standoff. When the ball is seen → **TRACK**.
- **TRACK** — a lateral PID (Kp = 3.0) slides the keeper along the goal to stay in
  front of the ball, with an **intercept boost** when the ball's bearing is changing
  fast. Hold depth meanwhile. On ball contact → **CLEAR**; if the ball is lost →
  GUARD.
- **CLEAR** — push forward (`CLEAR_PUSH_VY = 200`) for 450 ms to knock the ball away,
  steering toward the open corner if the camera is fitted → **RECOVER**.
- **RECOVER** — re-home depth and re-centre, then → GUARD (or on timeout).

**Staying on "the D".** No robot may be *fully* inside the penalty area, so the keeper
rides the **edge** of the goal area rather than sitting in it. The **back ultrasonic**
gives the continuous standoff (the depth-PID datum), while the **line ring** marks the
box edges: the FRONT board flags the up-field box line so the keeper does not drift
up-field past it, and the RIGHT/LEFT boards flag the side lines as corner limits. A
reflectance ring has no continuous distance, which is exactly why depth comes from the
ultrasonic and the line only hard-stops at the edges. A **back-wall safety cross-check**
never reverses into the own goal when the back wall is < 90 mm, a holonomic mixer with
output normalisation keeps motion smooth, and the keeper relaxes its heading when
stationary so it doesn't creep on gyro drift.

The clearing kicker is a four-phase machine tuned shorter than the attacker's:
`K_READY → K_ARMING (250 ms) → K_FIRING (100 ms) → K_COOLDOWN (2000 ms)`.

> `Defender_Full` shares the attacker's proven 9-byte line decoder, so the keeper's line
> edge limits use the same board→direction mapping as the attacker's fused escape.

---

## 8. Kicking — capture, solenoid, and safety

The kicker is a relay-switched solenoid on the **48 V** rail (relay IN1 = pin 22,
**active-HIGH** on this board, VCC 5 V). Capture is the main-board HC-SR04 in the
mouth. The firmware is deliberately conservative about energising a coil:

- **Capture debounce:** the ball must read `< 45 mm` for 2 consecutive pings before
  it counts as captured.
- **Pulse + cooldown:** the coil is on for a fixed `KICK_MS`, then forced to rest for
  `KICK_COOLDOWN_MS` before it can fire again.
- **Hard max-on cutoff:** a guard *above* the state machine force-releases the coil if
  it is ever energised longer than `KICK_MAX_ON_MS` (600 ms on the attacker), no
  matter what — a solenoid must never be left latched on.
- **Boot-safe:** the relay is driven to its release level **before** its pin becomes
  an output, so a mis-set polarity can't hold the coil on at power-up.

The kicker passes the rules' on-field power test (kick from inside one goal; the ball
must not rebound off the far goal back into your own).

---

## 9. Mechanical design

The chassis is a 4-omni-wheel diamond designed in **Fusion 360**
([`CAD/Fusion`](../CAD/Fusion)), with printable parts grouped by subsystem
([`CAD/Printable`](../CAD/Printable)). Printed parts include the side walls, omni wheels and
rollers, the base and top base, the **capture area** (the dribbler mouth that holds
the ball within the rules' ≤ 1.5 cm capture-zone limit), the IR cover, camera
holders, couplings, ultrasonic holders, and a **handle** (the rules require a stable
handle with 5 cm of clearance for lifting).

A notable sub-assembly is the **support-beam structure** (documented in
[`Legacy/CAD/Unused`](../Legacy/CAD/Unused)) that rigidly ties the **Main PCB → IR
cover → ultrasonic plate** together and clamps the previously-floating Power PCB at
all four corners, with screw pilots verified concentric to the boards' mounting
holes. Older motor/bracket and chassis studies are kept in
[`Legacy/CAD`](../Legacy/CAD).

---

## 10. Tuning reference

The constants most worth knowing, by file:

| Constant | Value | Where / why |
|---|---|---|
| Heading PID | Kp 6.0 / Ki 0 / Kd 0.5 | all main-board sketches |
| Control loop | 100 Hz | all main-board sketches |
| `BOUNDARY_MM` | 300 mm | attacker — line+US must agree under this to flee |
| `AVOID_CONFIRM` | 3 passes | attacker — boundary debounce |
| `KICK_AIM_TOL_DEG` | 5° | attacker — kick only when open corner is this aligned |
| `CAPTURE_BALL_MM` | 45 mm | capture mouth "ball present" |
| `KICK_MS` / cooldown / max-on | 500 / 1500 / 600 ms | attacker kicker |
| `BACK_STANDOFF_MM` | 220 mm | defender — back-ultrasonic standoff (depth datum) |
| `KP_LAT` / `KP_DEPTH` | 3.0 / 1.2 | defender lateral / depth PIDs |
| IR detect on/off | 60 / 35 | IR hysteresis |
| IR `NOISE_FLOOR` | 12 | IR ambient rejection |
| Line "sees line" | ≥ 2 white ch. | line boards |
| US range / rate | 20–2600 mm / ~50 Hz | ultrasonic board |

---

## 11. Known caveats (kept honest)

1. **Defender line frame** — `Defender_Full` decodes the same 9-byte mask frame the line
   boards emit (the old 8-byte depth contract is gone). Depth/standoff is the back
   ultrasonic; the line marks the box edges (§5.4, §7).
2. **Camera is read on the main board's Serial2**, not the IR-board header on pins
   34/35 (§4.4).
3. **Level-shift the ultrasonic TX** into the 3.3 V Teensy RX (§4.2).
4. **The ultrasonic side enum is robot-specific** (board mounted 180°); fix it in one
   place if the board is re-seated.
6. **Roles: flash-time by default, with optional radio switching** — the attacker and
   defender are the same robot with different main-board firmware. An optional
   nRF24L01+ link (`Firmware/Comms/RobotLink`) adds partner-aware role-switching: a
   robot that loses its partner's heartbeat covers the goal as keeper and resumes its
   base role at the next referee GO. Without the radio fitted, each robot plays its
   static flash-time role.

---

## 12. Pin map (main board, quick reference)

| Function | Teensy 4.1 pin(s) |
|---|---|
| Motor SLEEP (shared) | 6 |
| M1 / M2 / M3 / M4 IN1,IN2 | 2,3 / 4,5 / 9,10 / 11,12 |
| BNO055 IMU (Wire2) | SDA 25, SCL 24 |
| Capture HC-SR04 | TRIG 20, ECHO 21 |
| Kicker relay IN1 | 22 |
| IR link (Serial4 RX) | 16 |
| Ultrasonic link (Serial3 RX/TX) | 15 / 14 |
| Line link (Serial8 RX) | 34 |
| Camera link (Serial2 RX) | 7 |
| Comms module (Serial7 + GO/STOP) | RX7/TX7 + A12/A13 |
| OLED (optional) | 18 / 19 |

*All claims above trace to the firmware in [`Firmware/`](../Firmware) and the wiring
PDFs in [`PCB/Wiring/`](../PCB/Wiring). When in doubt, the code and the wiring are the
source of truth.*

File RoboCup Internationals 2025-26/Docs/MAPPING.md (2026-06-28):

# File & folder mapping (original → repo)

This repository is a **reorganised copy** of the original working folder
`RCJ Main 2026/RoboCup Internationals 2025-26` (plus two assets from just outside
it). The originals were never modified. This document records where everything went
and how it was renamed.

## Naming convention

- **Category folders** use readable **Title case**, with acronyms in caps:
  `Firmware`, `PCB`, `CAD`, `Docs`, `Legacy`, and within them `IR`, `Line`, `Main`,
  `Power`, `Ultrasonic`, `Fusion`, `Printable`, `Wiring`, `Fabrication`,
  `IR_Ball_Sensor`, `Line_Sensor`, `Motor_Current`, …
- **Sketch folders / KiCad projects** keep their base name (a sketch folder must
  match its `.ino`, and a KiCad project's `.kicad_pcb/.sch/.pro` must share one base
  name). Spaces became underscores throughout, so there are **no spaces anywhere**.

## Top-level

| Original | Repo |
|---|---|
| `…/Codes/` | `Firmware/` |
| `…/PCB/PCB Main/` | `PCB/` |
| `PCB/PCB Wiring/` *(outside base)* | `PCB/Wiring/` |
| `…/PCB/Zip PCB/` | `PCB/Fabrication/` |
| `…/CAD/` | `CAD/` |
| `VVS Ballers new logo.jpeg` *(outside base)* | `Docs/Images/VVS_Ballers_Logo.jpeg` |

## Firmware

| Original (`Codes/…`) | Repo (`Firmware/…`) |
|---|---|
| `Attacker/attacker_chase_aim_kick_line` | `Attacker/Attacker_Chase_Aim_Kick_Line` |
| `Defender/Defender_Full` | `Defender/Defender_Full` |
| `IR Code/Code2_Calibrated` | `IR_Ball_Sensor/Code2_Calibrated` |
| `IR Code/Code2_Refined` | `IR_Ball_Sensor/Code2_Refined` |
| `IR Code/Calibration` | `IR_Ball_Sensor/Calibration` |
| `Firmware Ultrasonic/Ultrasonic_NanoEvery` | `Ultrasonic/Ultrasonic_NanoEvery` |
| `Firmware Ultrasonic/Ultrasonic_Receiver_MainBoard` | `Ultrasonic/Ultrasonic_Receiver_MainBoard` |
| `Firmware Ultrasonic/README.md` | `Ultrasonic/README_ultrasonic.md` |
| `Line PCB Codes/line_pcb_detect` | `Line_Sensor/Line_PCB_Detect` |
| `Line PCB Codes/line_pcb_baseline` | `Line_Sensor/Line_PCB_Baseline` |
| `Line PCB Codes/line_pcb_raw_reader` | `Line_Sensor/Line_PCB_Raw_Reader` |
| `Camera Code/goal_cam.py` | `Camera/Goal_Cam.py` |
| `Camera Code/goal_cam_ball.py` | `Camera/Goal_Cam_Ball.py` |
| `Motor Current Control Code/motor_current_supervisor` | `Motor_Current/Motor_Current_Supervisor` |
| `Motor Current Control Code/motor_current_limit_1A` | `Motor_Current/Motor_Current_Limit_1A` |

## PCB

| Original (`PCB/PCB Main/…`) | Repo (`PCB/…`) |
|---|---|
| `Main_PCB 2.0` | `Main` (files → `Main_PCB_2.0.*`) |
| `IR_PCB` | `IR` |
| `Line_PCB` | `Line` |
| `Ultrasonic_PCB` | `Ultrasonic` |
| `Power PCB` | `Power` (files → `Power_PCB.*`) |

## CAD

| Original (`CAD/…`) | Repo (`CAD/…`) |
|---|---|
| `Fusion 1.0/` | `Fusion/` (files de-spaced, e.g. `Main Robot.f3z` → `Main_Robot.f3z`) |
| `Print/Print Round 1..3/` | `Printable/` — re-grouped **by subsystem** (`Chassis/`, `Drive/`, `Ball_Capture/`, `Sensor_Mounts/`) rather than by print round |

## Legacy (archived, superseded)

| Original | Repo (`Legacy/…`) |
|---|---|
| `Codes/Attacker/attacker_chase_aim_kick` | `Firmware/Attacker/Attacker_Chase_Aim_Kick` |
| `Codes/Attacker/ir_ball_chase_avoid_angle` | `Firmware/Attacker/IR_Ball_Chase_Avoid_Angle` |
| `Codes/Defender/Defender_NoLine` | `Firmware/Defender/Defender_NoLine` |
| `PCB/PCB Main/Main_PCB` | `PCB/Main_v1` |
| `CAD/Old Models/` | `CAD/Old_Models/` |
| `CAD/Not Using/` | `CAD/Unused/` |

## What was intentionally left out

Build/cache/version-control noise was not copied (it is regenerated, and is
`.gitignore`d): PlatformIO `.pio/` build trees, KiCad `*-backups/`, `.history/`
stores, `fp-info-cache`, `_autosave-*`, editor `.vscode/`, and Fusion script `out/`
directories.

The wider top-level working tree (`Codes/{In Progress, Motor Overheat, RCJ Codes
Refined, Test Codes}`, and the duplicate top-level `CAD/` and `PCB/`) was **not**
copied. Those originals remain untouched in their original location.

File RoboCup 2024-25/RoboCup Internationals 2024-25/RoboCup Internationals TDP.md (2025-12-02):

## Timestamp

*Timestamp*

7/12/2025 14:29:48

## Team Name

*What is your team's name?*

VVS Ballers

## League

*What league do you participate in?*

Lightweight League

## Country

*Where are you from?*

India

## Contact

*If other teams have questions about your robot, now or in the future, what email address(es) can we publish along with this document for people to reach you?

(You can put in multiple email addresses, like multiple team members, an email for the whole team or both. Feel free to share other ways of communication like Discord handles)*

kushals@vasantvalley.edu.in, shlokk@vasantvalley.edu.in, akshajg@vasantvalley.edu.in, akshaj.gupta28@gmail.com

## Social Media

*Team Social Media Links (if you have any)*

N/A

## Team Photo

*Upload a photo of your whole team with your mentor and robots

Note: This is not mandatory and will be published along with your TDP if you choose to upload something*

## Members & Roles

*What are the names of the team members and their role(s)?*

Kushal Sachdeva: Innovator and Mechanical Engineer
Shlok Karthik:  Robot Designer and Mechanical Engineer
Akshaj Gupta: Lead Programmer

## Meeting Frequency

*How often did your team meet?
(e.g. 90 minutes once per week or a day every weekend.)*

We met for 4 to 5 hours every day. On weekdays we worked in our school’s robotics room, and on weekends we met at our mentor’s academy for longer build and testing sessions.

## Meeting Place

*Where did you meet to work on your robot?
(e.g. a robotics room at school, at some other place, one of your homes, school library etc.)*

We primarily met at our school during weekdays and used our mentor’s robotics lab during weekends. Both spaces provided access to LEGO kits, practice fields, tools, and a quiet environment for collaboration.

## Start Date

*When did your team start working on this year's robot?*

We began working on this year’s robots in November 2024. We started with research and brainstorming, then moved into building and testing soon after.

## Past Competitions

*Which RoboCupJunior competitions have you competed in and in which leagues?*

Robocup Junior Regionals North India 2022: Soccer Lightweight League
Robocup Junior Regionals North India 2023: Soccer Lightweight League
Robocup Junior  Regionals North India 2024: Soccer Lightweight League
Roboup Junior Nationals India 2023: Soccer Lightweight League
Roboup Junior Nationals India 2024: Soccer Lightweight League

## Mentor Contribution

*Which parts of your work received the most contribution from your mentor?*

Our mentor played a crucial role in helping us integrate and debug our sensors, especially the IR Seeker and compass. He helped us purchase and configure a sensor multiplexer and ensured that our readings were accurate and stable. He also assisted in connecting our communication modules to meet the 2025 RoboCup requirements and supported us with physical robot adjustments and late-night coding sessions. Most importantly, he provided constant encouragement, shared his experience from past competitions, and helped guide our thinking during design discussions.

## Workload Management

*How did you manage the workload?*

We communicated through a dedicated WhatsApp group where we shared updates, photos, videos, and tasks. We also had a second group that included our parents and mentor for logistical planning such as travel and documentation. For project management, we used  GitHub to collaborate on code and keep track of versions. Even when we couldn't meet in person, we ensured progress by sharing our daily work digitally and supporting each other through messages and calls.

## AI Tools

*Which AI tools did you use?*

We used ChatGPT’s deep research model to better understand our sensors’ functions and troubleshoot sensor issues. It helped us understand how to interpret IR and compass readings, avoid interference, and write more accurate movement algorithms. This helped us accelerate our learning and apply more advanced logic than we initially planned.

## Robot1 Overall

*Robot 1 Overall View*



## Robot1 Front

*Robot 1 Front view*



## Robot1 Back

*Robot 1 Back view*



## Robot1 Top

*Robot 1 Top View*



## Robot1 Bottom

*Robot 1 Bottom View*



## Robot1 Right

*Robot 1 Right View*



## Robot1 Left

*Robot 1 Left View*



## Positioning & Movement

*How do you find your position inside the field and how do you use that position to move your robots around?*

We use a combination of an infrared (IR) seeker sensor and a compass sensor to determine our robot’s position and orientation on the field. The IR seeker divides the robot’s field of view into zones, numbered from 1 to 9 (with 5 being directly ahead and 0 being the blind zone). This allows us to detect the relative angle of the ball. In addition, we use a digital compass sensor that provides the robot’s heading relative to magnetic north. We calibrate the compass before each match so that the robot knows which direction corresponds to the opponent’s goal. The robot starts each match by facing forward in the calibrated direction. Using the heading from the compass and the zone from the IR seeker, the robot calculates a target direction to move. Our attacker uses this information to pivot and drive holonomically toward the ball, while constantly adjusting its orientation. The defender, which operates near our penalty area, uses the IR zone to move laterally (forward and backward) along the goal line, staying between the ball and our goal. Both robots use omnidirectional wheels that allow them to move in any direction without turning their body, enabling smooth and fast directional adjustments based on sensor feedback.

## Robot2 Overall

*Robot 2 Overall View*



## Robot2 Front

*Robot 2 Front view*



## Robot2 Back

*Robot 2 Back view*



## Robot2 Top

*Robot 2 Top View*



## Robot2 Bottom

*Robot 2 Bottom View*



## Robot2 Right

*Robot 2 Right View*



## Robot2 Left

*Robot 2 Left View*



## Mechanical Design

*How did you design the mechanical parts of your robots?*

We designed our robots through a process of group discussion, hands-on testing, and iteration using LEGO Mindstorms EV3 components. Although we considered advanced platforms like Raspberry Pi and custom PCBs at the beginning of the season, we ultimately decided to stick with EV3 because it was more time-efficient, it was also familiar to our team. We did not use any CAD software to design 3D models, as our design process was primarily physical. We built multiple prototypes using LEGO Technic parts and adjusted them based on how well they performed in real tests. For each major decision, such as motor placement or sensor positioning, we debated the pros and cons as a team and often voted on which configuration to pursue. For example, when designing the attacker robot, we discussed how to fit all four motors into a compact frame that still allowed space for sensors and cabling. We created a compact motor box using layered LEGO parts and gears to align with the omni-wheels. On the defender, we prioritized torque and balance, using three motors for movement and one additional motor to control the kicker mechanism. We continually refined both designs through testing on the field, improving things like weight distribution and gear ratios until we achieved the speed and stability we wanted.

## Build Method

*How did you build your design?*

Our robots were constructed entirely using LEGO EV3 and LEGO Technic parts, which we assembled by hand. We used the LEGO Mindstorms kit for structural elements, omni-wheels, sensors, and motors. We also used HiTechnic third-party sensors, such as the IR seeker and compass, which were compatible with the EV3 system. The entire build process was physical and modular—after creating a basic version of the robot, we tested its movement and behavior on the field and made iterative improvements. One example is the position of the IR seeker sensor: initially, we mounted it too low, and it had limited visibility of the ball. After testing, we moved it higher and angled it slightly downward, which improved its detection consistency. Similarly, for the defender, we added structural reinforcements to the kicker housing after noticing it flexed under repeated impacts. All changes were made manually, based on field performance, without outsourcing any manufacturing or using advanced tools like 3D printers or laser cutters.

## Motors & Reason

*How many motors have you used and why?*

We used four EV3 large motors in the attacker robot and four in the defender robot. In the attacker, all four motors are used for movement: each motor drives one of the four omni-directional wheels. This configuration gives the attacker high maneuverability and speed, which are critical for chasing the ball across the field. In the defender, we used three motors for movement. The three drive motors give the defender good torque and lateral control as it moves along the penalty box. We found that this distribution of motors allowed us to balance speed, control, and functionality for both roles. All motors are standard LEGO EV3 large motors (part number 45502), which were chosen for their compatibility, reliability, and sufficient torque for our robots' weight and tasks.

## Kicker Design

*If your robot has a kicker, explain how you designed and built the mechanics of the kicker*

Our defender robot features a unique unorthodox design which uses elastic potential energy stored in a rubber band. This system is lightweight, effective, and simple to reset after each use. We chose this design because it does not require complex electronics or additional sensors and keeps the overall weight of the robot within the lightweight league limit. During testing, we experimented with different rubber bands to achieve the right balance between power and control, and we reinforced the surrounding structure using LEGO beams to ensure durability. The kicker helps our defender quickly clear the ball from the penalty area without needing a dribbler or additional force.

## Dribbler Design

*If your robot has a dribbler, explain how you designed and built the mechanics of the dribbler.*

Our robots do not have a dribbler system.

## CAD Files

*CAD design files*

N/A

## Mechanical Innovation

*Mechanical Innovation*

One of the most effective mechanical innovations on our robots is the motor box structure used in the attacker. This design allows us to stack and align four motors in a compact space, keeping the overall footprint low while enabling omni-directional movement. By optimizing the positioning of gears and wheel mounts, we were able to reduce chassis height and improve balance. Another innovation is the elastic rubber band-based kicker used in the defender. This solution allows us to deliver fast, forceful kicks using stored mechanical energy, rather than relying on heavy, slow mechanical arms or additional electronics. These systems were developed through continuous iteration and problem-solving based on performance during test matches.

## Mechanical Photos

*Photos of your mechanical designs highlights*







## Electronics Block Diagram

*Provide us with a block diagram of your robot's electronics*



## Power Circuit

*How does your power circuits work?*

We use the official LEGO EV3 rechargeable battery pack, which supplies approximately 9V to the EV3 Brick. The brick then internally regulates voltage to provide appropriate power to sensors and motors. There are no external voltage regulators or converters, as the EV3 platform includes built-in power management. The battery is compact and fits neatly into the base of each robot, keeping the center of gravity low and consistent.

## Motor Drive Circuit

*How do you drive your motors? Explain the circuits you use for that*

All motors are connected directly to the EV3 Intelligent Brick’s motor ports. The EV3 Brick sends power and pulse-width modulation (PWM) signals to each motor through its internal motor driver circuits. No additional circuitry is required. We use the LEGO EV3 software to set motor speed, direction, and duration in code, which the brick interprets and executes.

## Microcontroller & Reason

*What kind of micro controller or board do you use for your robot? Why did you decide to use this part for your robot? If you have more than 1 processor, explain each one separately.*

We use the LEGO EV3 Intelligent Brick as our main and only microcontroller. It was chosen for its robust compatibility with LEGO motors and sensors, ease of programming, and past experience within our team. It allows us to focus more on optimizing performance and less on debugging hardware connections or programming syntax. Its built-in display, ports, and integrated motor control system make it an all-in-one solution suitable for rapid testing and iteration.

## Ball Detection

*How does your ball detection sensors and/or camera[s] work?*

We use the HiTechnic IR Seeker V2 sensor to detect the infrared signals emitted by the RoboCup soccer ball. This sensor is designed with five internal infrared detectors arranged in a circular pattern, each covering a different directional zone. The output of the sensor is a zone number ranging from 1 to 9, indicating the angle at which the ball is located relative to the robot. Zone 5 represents the forward direction, with zones 1 to 4 indicating positions to the left and zones 6 to 9 to the right. Zone 0 is used when the ball is not detected. The sensor also provides a signal strength reading, which we use to estimate how close the ball is. These readings are processed by the EV3 Brick, allowing the robot to turn toward and drive in the direction of the ball. The sensor is positioned on the front of the robot and angled slightly downward to maximize its field of view and reduce interference from ambient light. This system allows both the attacker and defender to identify the ball’s location and make real-time directional adjustments.

## Line Detection

*How does your line detection circuits work?*

Instead of relying on traditional white-line sensors, our robots use a combination of ultrasonic and infrared proximity sensors to detect the boundaries of the field. The ultrasonic sensors, mounted at the front and back of each robot, measure the distance to the nearest wall. As the robot approaches a wall, the sensor reading decreases. Our code responds to this by proportionally reducing the robot’s speed to prevent collisions or going out of bounds. We also tested infrared proximity sensors mounted on the sides of the robots to detect immediate obstacles or side boundaries, but found that the front and back ultrasonic sensors were sufficient for most scenarios. This approach reduces jerk near the field edges, allows smoother motion control, and avoids the complications of sensor drift on white surfaces. The system works reliably under different lighting conditions and has helped us avoid penalties during matches.

## Navigation/Position Sensors

*What sensors do you use for navigation and how are these sensors connected to your processor? What sensors do you use to find your position in the field? What about the direction your robot faces?*

We use three primary sensors for navigation: the HiTechnic compass sensor, the HiTechnic IR Seeker V2, and EV3 ultrasonic sensors. The compass sensor provides the robot’s heading in degrees (0–360) relative to magnetic north. The sensor autocalibrates  before each match to ensure that 0 degrees aligns with the direction of the opponent’s goal. The compass helps the robot stay oriented correctly on the field and ensures consistent behavior regardless of the robot’s starting position. The IR Seeker identifies the ball’s direction and is essential for positioning the robot relative to the game object. The ultrasonic sensors, mounted at the front and rear of the robot, help determine the robot’s proximity to field boundaries. All sensors are connected directly to the LEGO EV3 Brick using standard sensor ports. By combining data from all these sensors, the robot can navigate the field, track the ball, avoid leaving the play area, and stay correctly aligned at all times.

## Kicker Circuit

*How do you drive your kicker system? How does the circuit make the kicker work?*

Our kicker is entirely mechanical and does not rely on an electronic triggering circuit. It consists of a rubber band tensioned. the rubber band pushes the ball forward when it comes towards it. This elastic-powered system allows the robot to kick the ball with significant force. Because the system relies on mechanical energy rather than electrical actuation, it is both lightweight and consistent in performance.

## Dribbler Circuit

*How does your dribbler system work? What components and circuits did you use to drive it?*

We do not use a dribbler system in our robot.

## Schematics

*Schematics of your robot*

## PCB

*PCB of your robot*

## Innovation

*Innovations*

We are especially proud of our ultrasonic sensor-based proportional slowdown system for boundary detection. Instead of triggering abrupt stops or turns, the robot scales down its speed as it approaches the wall. This makes the movement smoother and allows more accurate sensing. It also reduces the risk of going out of bounds and makes the robot more stable under pressure. Implementing this control logic using the limited processing capabilities of the EV3 Brick was a major accomplishment for our team.

## Circuit Photos

*Photo of your circuit boards highlights*





## Motor Control

*How do you use your processor to move your motors?*

The LEGO EV3 Intelligent Brick controls all motors using built-in programming blocks. We use the graphical EV3 software to set motor speed, direction, duration, and rotation. For example, if the robot needs to rotate toward the ball, we set the left and right drive motors to opposite speeds until the IR zone reading centers at 5. When driving holonomically, each wheel receives a different speed value to enable lateral or diagonal movement. The processor continuously reads sensor values, calculates the required motor response, and sends control signals to the motors in real time. We use loops and conditional logic to handle continuous decision-making during gameplay, and the EV3 Brick interprets all commands without the need for external circuits.

## Ball Detection Method

*How do you find where the ball is? How do you read the data from the ball detection sensors or camera?*

We use the HiTechnic IR Seeker V2 to detect the ball’s location. The sensor outputs a directional zone (1–9) and a signal strength value, both of which are read by the EV3 Brick using I²C communication. Zone 5 indicates that the ball is directly in front of the robot, while zones 1–4 represent angles to the left and zones 6–9 represent angles to the right. Zone 0 indicates that the ball is not detected. These values are read in each loop cycle and used to determine whether the robot should rotate, drive forward, or make lateral adjustments. The attacker uses this information to turn toward the ball and drive in a straight or angled path. The defender uses the same data but interprets it differently to stay aligned along the goal area.

## Ball Catch Algorithm

*How does your algorithm work to catch the ball? Is there a difference between your robots in how they move towards the ball? Explain the differences.*

Yes, each robot uses a different algorithm tailored to its role. The attacker uses a triangulation-based pursuit algorithm. It reads the IR zone value to determine the ball’s angle and uses the compass to maintain orientation. If the ball is detected to the left or right, the robot rotates holonomically in that direction while still facing forward. As the ball approaches zone 5, the attacker accelerates forward, slows down slightly near the ball, and attempts to push it directly toward the goal. The defender, on the other hand, does not rotate as much. It starts aligned sideways and moves forward or backward along the penalty box. Its algorithm constantly checks the IR zone and signal strength. If the ball enters a defined zone of danger (strong signal in zone 4, 5, or 6), the defender advances slightly to intercept and activate the kicker if needed. These complementary algorithms allow both robots to work independently but in sync during gameplay.

## Line Algorithm

*How does your robot find the lines to stay inside the field? What algorithms do you use to avoid going out of bounds?*

Our robots use ultrasonic distance sensors instead of line sensors to avoid going out of bounds. Each robot has front and rear ultrasonic sensors that continuously measure the distance to nearby walls. When the robot approaches the wall, the sensor reading drops below a threshold (e.g., 30 cm), triggering a proportional response in our code. The robot reduces speed gradually as it nears the wall, then either stops or reverses direction. This gradual slowdown helps reduce abrupt movement, minimizes the chance of sensor misreading, and improves overall stability. We chose this approach because ultrasonic sensors are less sensitive to ambient lighting conditions and do not rely on contrast between the white boundary lines and the playing surface. It also allows smoother, more reliable boundary control in real match conditions.

## Goal Algorithm

*What algorithms do you use to score goals? How do you use your kicker and dribbler to handle the ball?*

Our attacker does not use a kicker or dribbler, so the algorithm relies on clean pursuit and momentum. The robot tracks the ball using the IR seeker, aligns toward the goal using the compass sensor, and drives with increasing speed. Once the ball is pushed past the halfway point and near the opponent’s penalty box, the robot accelerates sharply and allows the ball’s momentum to carry it into the goal. The idea is to maintain orientation, avoid interference, and use the robot’s own speed as a driving force. The defender can also contribute by kicking the ball from our half to the opponent’s side using the elastic-powered kicker, especially during counterattacks.

## Defense Algorithm

*What algorithms do you use to avoid the opponent team scoring? How do your robots defend your own goal?*

Our defender follows a simple but effective algorithm. It starts positioned sideways along our penalty box and moves laterally along the line. When the IR sensor detects the ball approaching from zone 4, 5, or 6 with strong signal strength, the robot moves slightly forward to intercept. If the ball enters the capture zone, the robot activates the rubber band kicker using a timed motor rotation to clear the ball. If no ball is detected, the robot remains centered. The use of a compass allows the robot to maintain consistent alignment, while the ultrasonic sensor ensures it does not move beyond the allowed area. This reactive but stable behavior enables the defender to effectively block and clear incoming threats.

## Robot Communication

*Do your robots communicate with each other? How do you use this communication to your advantage?*

No, our robots do not use any form of wireless or inter-robot communication. Each robot is programmed to fulfill a distinct role and operates autonomously based on its own sensor inputs. However, the behaviors are coordinated during design so that the attacker and defender do not interfere with each other. The attacker always focuses on ball pursuit and scoring, while the defender remains within the penalty area. This separation of roles has proven to be effective and avoids any risk of collisions or command conflicts.

## Innovation2

*Innovations*

Our most innovative algorithm is the one that combines compass and IR seeker data to create a dynamic triangulation system. By treating the compass as a fixed heading and the IR zone as a relative direction, we calculate precise movement vectors that allow the robot to approach the ball from optimal angles. We also implemented smoothing to reduce jitter when the ball hovers between two zones. These strategies make our robot faster and more stable in tracking the ball, even during complex plays.

## GitHub Link

*GitHub link*

https://github.com/Akshaj-Gupta/ev3-inernat2025-brazil.git

## BOM

*Bill of Materials (BOM)*

[https://drive.google.com/open?id=1Z6dYU2flA_F0CtbMPMIJH1wBlCQ4SZ1G](https://drive.google.com/open?id=1Z6dYU2flA_F0CtbMPMIJH1wBlCQ4SZ1G)

## Cost

*How much did it cost you to build your robots?*

Robots (final components currently inside both robots): approximately £1,000
Includes the EV3 Bricks, motors, omni-wheels, sensors, LEGO Technic structural parts, and wiring.

Experiments (failed prototypes, spare parts, replacements): approximately £500
Includes trial chassis, alternate kicker prototypes, damaged motors, and sensor.

Environment (practice field, IR ball, carpet, tools, etc.): approximately £200
Covers cost of building a full-size training field, purchasing an IR ball, and basic testing equipment.

## Funding

*How did you gathered the funds to build the robots?*

100% Parents

## Affordability

*How affordable was it to compete in RoboCupJunior Soccer?*

4

## Answer Check

*Have you checked all of your answers?*

Yes!

## Publication Consent

*We publish TDPs and posters during or after the competition as described in the beginning*

Yes, we acknowledge everything submitted in the above form can be published.

## Email Address

*Email Address*

kushals@vasantvalley.edu.in

## TDP File

*TDP File Upload (Not required)*

## Extra Column

*Column 67*

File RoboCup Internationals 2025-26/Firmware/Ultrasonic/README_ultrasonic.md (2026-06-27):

# Ultrasonic Wall / Obstacle Ranging Board — Arduino Nano Every

Firmware for the **Ultrasonic_PCB**: an **Arduino Nano Every (ABX00028,
ATmega4809)** carrier with **four HC-SR04** sensors, one on each side. It ranges
the four field walls / nearby robots and streams the four distances to the main
PCB over a **framed, CRC-checked UART packet** — built for a fast robot on the
**182 cm × 243 cm** field, so the values are *accurate, fast, and correct*.

Two sketches, each opens directly in the **Arduino IDE** and also builds under
PlatformIO:

| Folder (open the matching `.ino`) | What it is |
|---|---|
| [`Ultrasonic_NanoEvery/`](Ultrasonic_NanoEvery) | **The board firmware.** Pings the 4 sensors, filters, and emits the packet on `Serial1`. |
| [`Ultrasonic_Receiver_MainBoard/`](Ultrasonic_Receiver_MainBoard) | **Reference parser** for the main board — drop `ultrasonicPoll()` into your main firmware. |

---

## 1. Hardware — pin map (single source of truth)

Read straight from `Ultrasonic_PCB.kicad_pcb` (verified against the routed
netlist, not guessed). Index order is **clockwise: FRONT, RIGHT, BACK, LEFT**.

| Idx | Side | PCB sensor | Board edge | TRIG | ECHO |
|---|---|---|---|---|---|
| 0 | FRONT | U4 | top | **D8** | **D9** |
| 1 | RIGHT | U3 | right | **D4** | **D5** |
| 2 | BACK | U2 | bottom | **D6** | **D7** |
| 3 | LEFT | U1\* | left | **D2** | **D3** |

\*The PCB labels a *sensor* as `U1`; the Arduino module's reference is
`"Arduino Nano"`. The four sensors sit at the four board edges around the Nano.

**Other nets**
- **UART to main PCB** — connector **J2**: pin 1 → **D0 (RX)**, pin 2 → **D1
  (TX)**. On the Nano Every these are the hardware **`Serial1`** UART, so the USB
  `Serial` stays free for debugging.
- **Power** — connector **J1**: pin 1 → **VIN**, pin 2 → **GND**. Every HC-SR04
  `VCC` is tied to the VIN rail, so feed J1 a clean **5 V** (HC-SR04 needs 5 V;
  the Nano Every's regulator also accepts it on VIN). Common GND with the main
  board is required for the UART.

> **"Which sensor is FRONT?"** `FRONT` is defined here as the board edge carrying
> **U4**. The true forward direction depends on how you bolt the board into the
> robot. If your nose points at a different edge — or the board is mounted
> components-down, which swaps LEFT/RIGHT — just re-order the four entries in
> `TRIG_PIN[]`/`ECHO_PIN[]` in `config.h` (keep each TRIG+ECHO pair together) so
> index 0 faces forward, then bench-check (§6).

---
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

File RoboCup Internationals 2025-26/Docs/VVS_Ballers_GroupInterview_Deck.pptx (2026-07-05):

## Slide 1

VVS Ballers

RoboCupJunior Soccer · IR League (Lightweight)

International Finals 2025-26 · India


Kushal Sachdeva & Darsh Goel with both robots

Kushal Sachdeva — Team Lead · Electrical, Software & CAD

Darsh Goel — Mechanical & CAD

2

ROBOTS

5

CUSTOM PCBs

16

IR SENSORS

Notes: BOTH present (Kushal opens). ~25s: Hi, we're VVS Ballers from India in the IR League. I'm Kushal - team lead, electronics/firmware/CAD. I'm Darsh - mechanical and CAD. We field TWO robots on one shared platform: one attacker, one defender, trading roles automatically if a robot goes down. Almost everything - wheels, five PCBs, all firmware - we built from scratch this season.
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

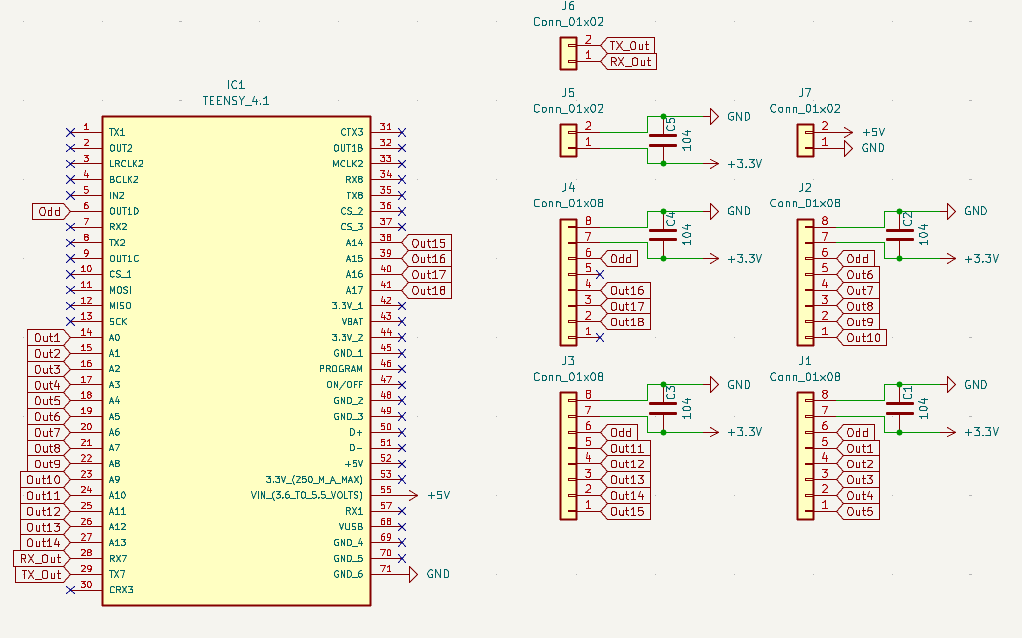
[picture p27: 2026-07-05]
RoboCup Internationals 2025-26/Docs/Images/Electronics/Line_Schematic.png

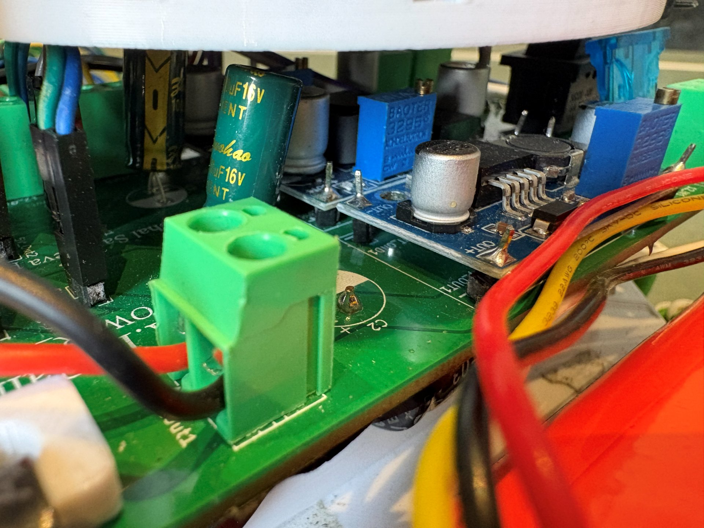
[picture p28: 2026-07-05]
RoboCup Internationals 2025-26/Docs/Images/Electronics/Power_PCB_Photo.jpg

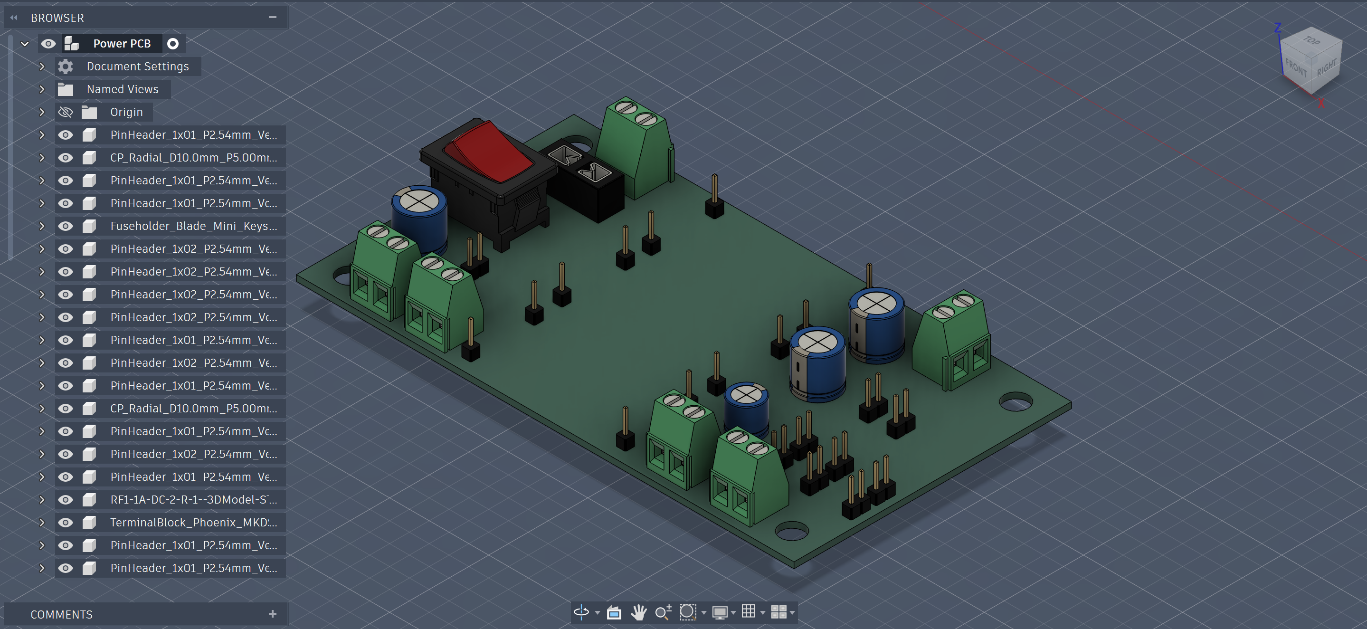
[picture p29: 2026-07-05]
RoboCup Internationals 2025-26/Docs/Images/Electronics/Power_PCB_3D_Model.png

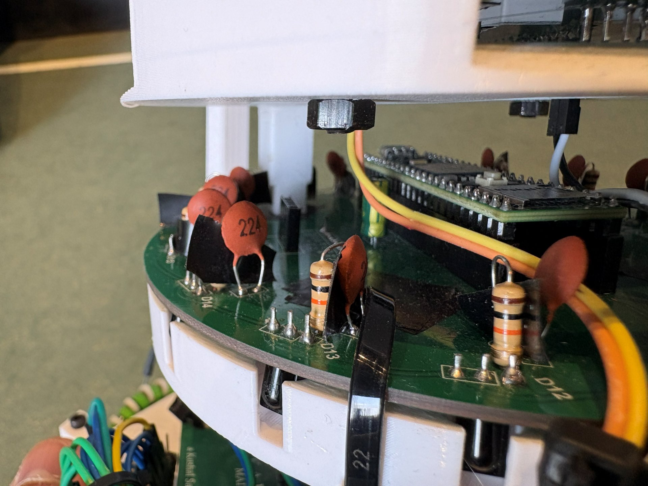
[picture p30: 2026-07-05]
RoboCup Internationals 2025-26/Docs/Images/Electronics/IR_PCB_RC_Circuit.jpg

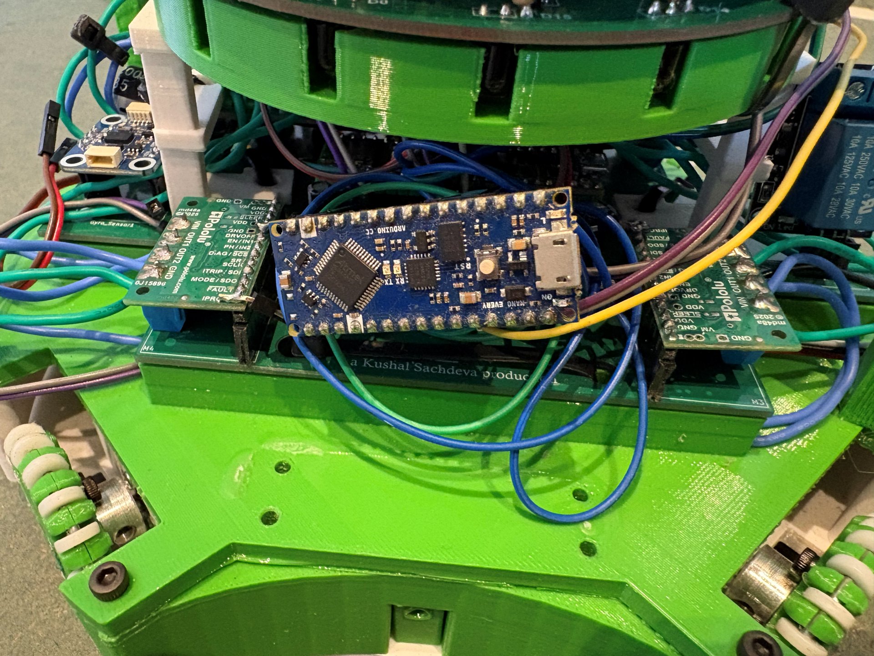
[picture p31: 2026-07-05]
RoboCup Internationals 2025-26/Docs/Images/Electronics/Arduino_Nano_Current_Controller.jpg

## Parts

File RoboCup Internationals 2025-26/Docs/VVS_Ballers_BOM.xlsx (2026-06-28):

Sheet: BOM
Name of the part | How many used | Link where it can be bought | Cost of one piece | Total cost per part | Total cost of 2 Robots
Teensy 4.1 (main, IR-ring & line-ring boards — 3 per robot) | 6 | https://www.pjrc.com/store/teensy41.html | 32.00 € | 192.00 €
Arduino Nano Every (ultrasonic board + motor-current limiter — 2 per robot) | 4 | https://store.arduino.cc/products/arduino-nano-every | 16.00 € | 64.00 €
BNO055 9-DOF IMU (heading) | 2 | https://www.adafruit.com/product/2472 | 25.00 € | 50.00 €
TSSP58038 IR receiver (16-sensor ball ring) | 32 | https://www.pololu.com/product/2579 | 1.20 € | 38.40 €
QTR-MD-05A reflectance array (4 per robot, line ring) | 8 | https://www.pololu.com/product/4351 | 8.00 € | 64.00 €
HC-SR04 ultrasonic (4 ring + 1 capture mouth = 5 per robot) | 10 | https://www.adafruit.com/product/3942 | 2.00 € | 20.00 €
DRV8263H brushed motor driver (4 per robot) | 8 | https://www.ti.com/product/DRV8263 | 5.00 € | 40.00 €
Pololu 20D mm metal gearmotor 12V (drive, 4 per robot) | 8 | https://www.pololu.com/category/115/20d-mm-metal-gearmotors | 26.00 € | 208.00 €
Omni wheels — self-designed, 3D-printed PETG + TPU (4 per robot) | 8 | made at home | 10.00 € | 80.00 €
OpenMV H7 R2 camera (goal vision) | 2 | https://openmv.io/products/openmv-cam-h7-r2 | 80.00 € | 160.00 €
Solenoid kicker actuator (push-type, 48 V) | 2 | https://www.aliexpress.com (push-pull solenoid) | 12.00 € | 24.00 €
Relay module (kicker drive) | 2 | https://www.aliexpress.com (1-ch relay module) | 3.00 € | 6.00 €
Main PCB — custom, JLCPCB | 2 | https://jlcpcb.com | 3.42 € | 6.84 €
IR PCB — custom, JLCPCB | 2 | https://jlcpcb.com | 3.07 € | 6.14 €
Line PCB — custom, JLCPCB | 2 | https://jlcpcb.com | 3.82 € | 7.64 €
Ultrasonic PCB — custom, JLCPCB | 2 | https://jlcpcb.com | 3.04 € | 6.08 €
Power PCB — custom, JLCPCB | 2 | https://jlcpcb.com | 2.65 € | 5.30 €
48 V step-up (boost) converter — solenoid supply | 2 | https://www.aliexpress.com (XL6019/boost module) | 6.00 € | 12.00 €
5 V step-down (buck) converter | 2 | https://www.aliexpress.com (buck module) | 3.00 € | 6.00 €
3.3 V step-down (buck) converter | 2 | https://www.aliexpress.com (buck module) | 3.00 € | 6.00 €
LiPo battery 12 V (3S) | 2 | https://www.aliexpress.com (3S LiPo) | 25.00 € | 50.00 €
Battery capacity indicator | 2 | https://www.aliexpress.com | 3.00 € | 6.00 €
Main power switch + fuse holder | 2 | https://www.aliexpress.com | 3.00 € | 6.00 €
3D-printed chassis & mounts — PETG (per robot set) | 2 | made at home | 20.00 € | 40.00 €
Misc: bulk capacitors, connectors, headers, wiring (per robot) | 2 | https://www.aliexpress.com | 15.00 € | 30.00 €
TOTAL (both robots) |  |  |  | 1134.40 € | 1134.40 €

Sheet: Notes & price sources
VVS Ballers — Bill of Materials (RoboCupJunior Soccer Infrared, Internationals 2025-26)
Format follows the official BOM template columns exactly. Quantities are for the SET OF 2 ROBOTS
(per-robot count x 2), matching the template (e.g. 4 motors/robot -> 8).
Currency: EUR. 1 EUR = 1.14 USD (per the form's stated example rate — confirm current rate at submission).
PRICES ARE RESEARCHED MARKET ESTIMATES, not the team's actual paid invoices. The BOM total below
(~EUR 1,160) is lower than the team's stated ~EUR 700/robot (=1,400) — likely due to local/import
pricing, shipping and duties in India. >>> Replace unit prices with your actual paid prices before submitting.
Items to VERIFY / confirm (flagged):
- Pololu gearmotor: confirm exact model/gear ratio & price (the template example shows a Pololu motor at 34,91 EUR).
- QTR-MD-05A: confirm Pololu SKU (#4351) and price.
- DRV8263H: confirm whether bought as bare IC or breakout module, and unit price.
- BNO055: genuine Adafruit (~25 EUR) vs GY-BNO055 clone (~12 EUR) — pick what you used.
- Solenoid: confirm exact actuator model, stroke/force and price.
- Custom PCB unit prices (JLCPCB) depend on order qty (MOQ 5) and assembly — use your invoice.
- OpenMV H7: confirm if the DEFENDER also carries a camera, or only the attacker (affects qty).
- LiPo battery: confirm cell count (3S/4S) and capacity.
PCB PRICES CONFIRMED from JLCPCB invoice (orders Y16/Y17/Y19/Y24/Y25):
Main 2.0 $3.90, IR $3.50, Line $4.36, Ultrasonic $3.46, Power $3.02 per board (MOQ 5 each).
Converted USD->EUR at 1 EUR = 1.14 USD. Qty = 2 (boards in the 2 robots); extra 3 of each are spares.
JLC merchandise $91.20 + shipping $55.87 = $147.07; shipping & spare boards go under Spare Parts/Experiments, not per-part.

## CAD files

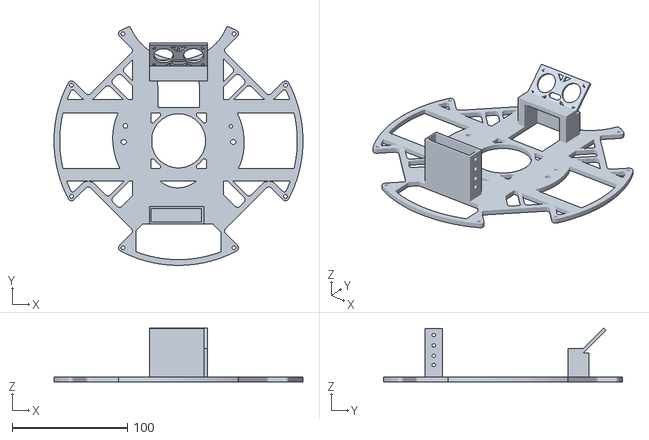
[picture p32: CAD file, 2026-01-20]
RoboCup Nationals 2025-26/3D Models/Top Cover.stl
215.9 x 206.9 x 46.6

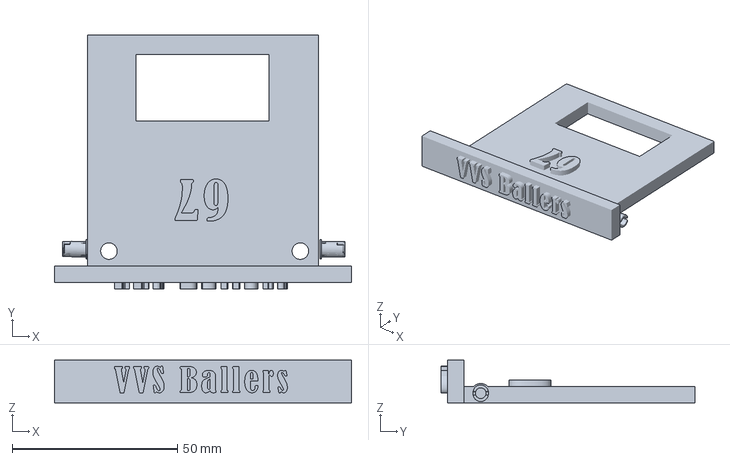
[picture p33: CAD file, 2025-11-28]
RoboCup Regionals 2025-26/RoboCup Regionals 3D Models/Robocup Regionals Kicker.3mf
90.0 x 77.0 x 13.0 mm

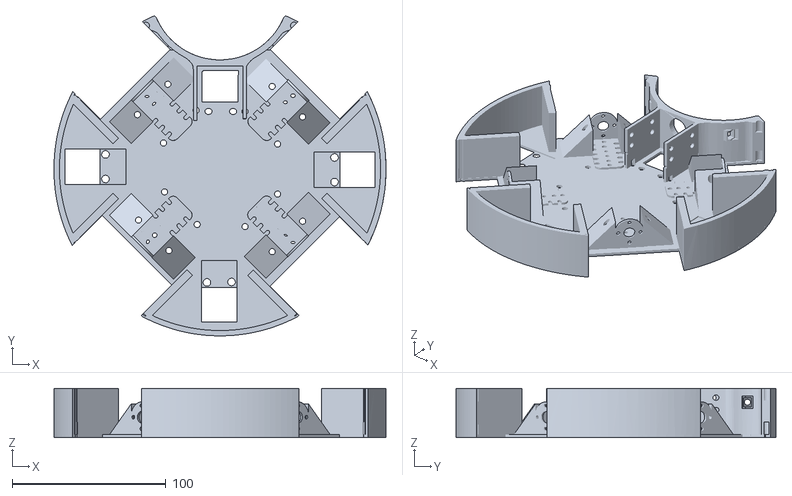
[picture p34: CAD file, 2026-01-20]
RoboCup Nationals 2025-26/3D Models/Final Base.stl
216.0 x 208.0 x 32.0

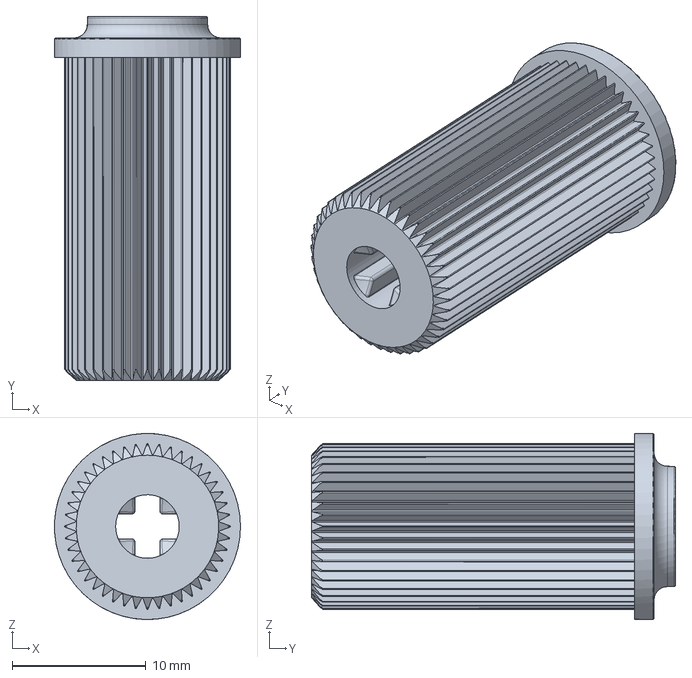
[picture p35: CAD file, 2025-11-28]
RoboCup Regionals 2025-26/RoboCup Regionals 3D Models/Omni Wheel Lego Shaft Coupling.stp
13.9 x 27.2 x 13.9 mm

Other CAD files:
RoboCup Internationals 2025-26/PCB/Main/Main_PCB_2.0.step
RoboCup Internationals 2025-26/CAD/Printable/Ball_Capture/Capture_Area_2.0.stl
RoboCup Internationals 2025-26/CAD/Printable/Chassis/Top_Base_Fixed__2.stl
RoboCup Internationals 2025-26/CAD/Printable/Drive/Omni_Wheel_Roller.stl
RoboCup Internationals 2025-26/CAD/Printable/Sensor_Mounts/Camera_Holder.stl
RoboCup Internationals 2025-26/PCB/IR/IR_Borred.step
RoboCup Internationals 2025-26/PCB/Line/Line_PCB.step
RoboCup Internationals 2025-26/PCB/Power/Power_PCB.step
RoboCup Internationals 2025-26/PCB/Ultrasonic/Ultrasonic_PCB.step
RoboCup Internationals 2025-26/CAD/Printable/Ball_Capture/Capture_Area_3.0__1.stl
RoboCup Internationals 2025-26/CAD/Printable/Chassis/Top_Base_1.0.stl
RoboCup Internationals 2025-26/CAD/Printable/Drive/2025_Lightweight_-_Wheel_Back.STL
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

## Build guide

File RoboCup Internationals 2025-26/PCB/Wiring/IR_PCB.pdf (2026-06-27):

# IR PCB

## 0) Powering (From Power PCB)

Power PCB (5V) → Teensy VIN
Power PCB (GND) → Teensy GND

Power PCB (3.3V) → IR PCB 3.3V rail Power PCB (GND) → IR PCB GND rail

Entry bulk capacitor (your single cap)

- 100 µF / 25V from 3.3V → GND at the 3.3V entry

## 1) Power to every TSSP58038 (from Teensy 3.3V)

Teensy 3.3V → IR PCB 3.3V rail (Vin for all TSSP58038)
Teensy GND → IR PCB GND rail

Oled Screen VCC → IR PCB 3.3V rail
Oled Screen GND → IR PCB GND rail

For each sensor:

- TSSP58038 Vin (pin 3) → IR PCB 3.3V rail
- TSSP58038 GND (pin 2) → IR PCB GND rail

## 2) Sensor outputs (D0–D15 nodes) → Teensy analog pins

Each channel is (already on your PCB):
IRoutX → 10k → Dx, and Dx → 0.22 µF → GND

Wire Dx to Teensy 4.1:

- D0 → A0
- D1 → A1
- D2 → A2

- D3 → A3
- D4 → A4
- D5 → A5
- D6 → A6
- D7 → A7
- D8 → A8
- D9 → A9
- D10 → A10
- D11 → A11
- D12 → A12
- D13 → A13
- D14 → A14
- D15 → A15

## 3) UART to the other Teensy (ball direction link) — Serial2 (TX2/RX2)

Using Serial2 on Sensor Teensy4.1

- TX2 (pin 8) → Main Teensy RX
- RX2 (pin 7) ← Main Teensy TX

Camera to IR PCB Teensy :

RX_C → Pin 34

TX_C → Pin 35

RST → 1K ohm resistor → Pin 36

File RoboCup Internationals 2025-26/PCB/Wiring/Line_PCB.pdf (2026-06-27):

# Line PCB

A) Power: Power PCB → this PCB rails (5V for Teensy, 3.3V for sensors)
1. Power input to this PCB (from Power PCB)
Power PCB 5V OUT → This PCB 5V_RAIL
Power PCB GND → This PCB GND_RAIL
Power PCB 3.3V OUT → This PCB 3.3V_SENS_RAIL
Power PCB GND → This PCB GND_RAIL (common ground everywhere)
2. Teensy power (on this PCB)
5V_RAIL → Teensy VIN
GND_RAIL → Teensy GND
3. Bulk capacitor on sensor 3.3V rail (on this PCB) Capacitor C1 = 100µF/25V electrolytic
C1 + → 3.3V_SENS_RAIL
C1 − → GND_RAIL
B) QTR-MD-05A Sensors (4 boards) power + decoupling + control

For EACH QTR board (QTR1, QTR2, QTR3, QTR4):

1. Power
QTRx VCC → 3.3V_SENS_RAIL
QTRx GND → GND_RAIL
2. Ceramic capacitor close to the sensor connector (on this PCB) Capacitor C4/C5/C6/C7 = 0.1µF (100nF) ceramic
Cap one side → 3.3V_SENS_RAIL
Cap other side → GND_RAIL
3. Emitter control
QTRx CTRL_ODD → Teensy pin D6 (shared line to all 4 boards) QTRx CTRL_EVEN → NC
C) Analog outputs wiring (18 used, 2 not connected)

QTR #1 outputs → Teensy analog pins QTR1 OUT0 → Teensy A0
QTR1 OUT1 → Teensy A1
QTR1 OUT2 → Teensy A2
QTR1 OUT3 → Teensy A3
QTR1 OUT4 → Teensy A4

QTR #2 outputs → Teensy analog pins QTR2 OUT0 → Teensy A5
QTR2 OUT1 → Teensy A6
QTR2 OUT2 → Teensy A7
QTR2 OUT3 → Teensy A8
QTR2 OUT4 → Teensy A9

QTR #3 outputs → Teensy analog pins QTR3 OUT0 → Teensy A10
QTR3 OUT1 → Teensy A11
QTR3 OUT2 → Teensy A12
QTR3 OUT3 → Teensy A13
QTR3 OUT4 → Teensy A14

QTR #4 outputs → Teensy analog pins (3 used, 2 dropped) QTR4 OUT0 → NC
QTR4 OUT1 → Teensy A15
QTR4 OUT2 → Teensy A16
QTR4 OUT3 → Teensy A17
QTR4 OUT4 → NC
D) UART pins
Teensy TX7 → Main PCB RX
Teensy RX7 → Main PCB TX

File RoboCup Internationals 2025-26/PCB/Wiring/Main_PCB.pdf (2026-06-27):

# Main PCB

## Power:

12V

- Power PCB 12V→ Switch → Capacitor + →12V Rail
- Power PCB GND →Capacitor - → GND rail

5V

- Power PCB 5V→ Switch → Capacitor + → 5V Rail
- Power PCB GND →Capacitor - → GND rail

3.3V

- Power PCB 3.3V→ Switch → Capacitor + → 3.3V Rail
- Power PCB GND →Capacitor - → GND rail

Teensy 4.1

- VIN →5V Rail
- GND → GND rail

## Sensors etc:

Gyro(Adafruit BNO055)

- VIN →3.3V
- GND → GND rail
- SCL→ Teensy pin 24
- SDA→ Teensy pin 25

Ultrasonic(HC-SR04)

- VCC →3.3V
- Trig→ Teensy pin 20
- Echo→ Teensy pin 21
- GND → GND rail

Relay Module

- VCC → 5V Rail
- IN1 → Teensy pin 22
- GND→ GND_Rail

Line PCB

- TX_L → RX8
- RX_L →TX8

IR PCB

- TX_IR → RX4
- RX_IR →TX4

Oled Screen

- SDA_S→ Teensy pin 18
- SCL_S →Teensy pin 19

Ultrasonic PCB

- TX_U → 15
- RX_U →14

### RoboCup Communication Module

- https://github.com/robocup-junior/soccer-communication-module GND → GND rail
LOGV → 3.3V rail
- Start/Stop outputs (GO/STOP)
OUT1 → Teensy A12
OUT2 → Teensy A13
- UART (Serial7)
TX (module) → RX7 (Teensy) RX (module) → TX7 (Teensy)

## 2) Motor drivers

## DRV8263H #1 (Motor 1)

Power

- VM/VIN → 12V rail
- GND → GND rail
- VDD → 3.3V rail

Mode / enable (recommended)

- MODE → GND (PH/EN style using IN1/IN2 pins)
- SR → GND
- DRVOFF → GND
- SLEEP → Teensy pin 6 (shared with all drivers)

Control

- 1_IN1 → Teensy pin 2
- 1_IN2 → Teensy pin 3

Motor

- OUT1, OUT2 → Pololu 12V 1.6A Motor 1

## DRV8263H #2 (Motor 2)

Power

- VM/VIN → 12V rail
- GND → GND rail
- VDD → 3.3V rail

Mode / enable (recommended)

- MODE → GND
- SR → GND
- DRVOFF → GND
- SLEEP → Teensy pin 6 (shared)

Control

- 2_IN1 → Teensy pin 4
- 2_IN2 → Teensy pin 5

Motor

- OUT1, OUT2 → Pololu 12V 1.6A Motor 2

## DRV8263H #3 (Motor 3)

Power

- VM/VIN → 12V rail
- GND → GND rail
- VDD → 3.3V rail

Mode / enable (recommended)

- MODE → GND
- SR → GND
- DRVOFF → GND
- SLEEP → Teensy pin 6 (shared)

Control

- 3_IN1 → Teensy pin 9
- 3_IN2 → Teensy pin 10

Motor

- OUT1, OUT2 → Pololu 12V 1.6A Motor 3

## DRV8263H #4 (Motor 4)

Power

- VM/VIN → 12V rail
- GND → GND rail
- VDD → 3.3V rail

Mode / enable (recommended)

- MODE → GND
- SR → GND
- DRVOFF → GND
- SLEEP → Teensy pin 6 (shared)

Control

- 4_IN1 → Teensy pin 11
- 4_IN2 → Teensy pin 12

Motor

- OUT1, OUT2 → Pololu 12V 1.6A Motor 4

## Optional (leave unconnected if you don’t need them)

- FAULT → Teensy input (optional)
- IPROPI → Teensy analog input (optional current sense)
- DIAG → optional / leave default

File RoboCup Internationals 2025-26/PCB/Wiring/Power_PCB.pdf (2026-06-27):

# Power PCB

## Power PCB

Battery input

- BAT+ (12V IN) → Fuse → Main Power Switch → SW_12V+ node (switched 12V+)
- BAT− (GND IN) → GND BUS (unswitched ground)

Usual best practice: fuse and switch the positive lead only. Ground stays common.

## Switched 12V distribution (the backbone)

From SW_12V+ node:

- → Main 12V Rail Output (to Main PCB 12V IN)
- → 5V Step-Down Converter VIN+
- → 3.3V Step-Down Converter VIN+
- → 48V Step-Up Converter VIN+
- → Battery Capacity Indicator + (sense/input)

From GND BUS:

- → Main PCB GND
- → All converter VIN− / GND
- → Battery indicator GND
- → All output grounds (shared)

## Converter wiring

1) Step-Down Converter (5V)

Input

- VIN+ → SW_12V+
- VIN− → GND BUS

Output

- VOUT+ → 5V RAIL (Power PCB)
- VOUT− → GND BUS

Capacitors (right after converter output)

- C5V_BULK: 470µF–1000µF electrolytic across 5V RAIL ↔ GND BUS

5V outputs (x3)

- 5V_OUT1+ → Main PCB 5V
- 5V_OUT2+ → IR PCB 5V
- 5V_OUT3+ → Line PCB 5V
- 5V_OUT4+ → Ultrasonic PCB 5V
- 5V_OUT5+ → Open MV H7 R2 camera 5V
- All their grounds → GND BUS (or provide 5V_OUTx− pins tied to GND BUS)
2) Step-Down Converter (3.3V)

Input

- VIN+ → SW_12V+
- VIN− → GND BUS

Output

- VOUT+ → 3.3V RAIL (Power PCB)
- VOUT− → GND BUS

Capacitors (right after converter output)

- C3V3_BULK: 470µF–1000µF electrolytic across 3.3V RAIL ↔ GND BUS

3.3V outputs (x3)

- 3V3_OUT1+ → Main PCB 3.3V
- 3V3_OUT2+ → IR PCB 3.3V
- 3V3_OUT3+ → Line PCB 3.3V
- Grounds → GND BUS
3) Step-Up Converter (48V) (for solenoid supply)

Input

- VIN+ → SW_12V+
- VIN− → GND BUS

Output

- VOUT+ → 48V RAIL
- VOUT− → GND BUS (shared ground unless you are intentionally isolating—most builds keep common ground)

Capacitors (right after converter output)

- C48V_BULK: (typical) 100µF–470µF electrolytic rated ≥63V across 48V RAIL ↔ GND BUS

48V output (x1)

- 48V_OUT+ → Solenoid Relay Module / Solenoid supply
- 48V_OUT− → GND BUS

## 12V output section

12V Out x1 (to Main PCB)

- 12V_OUT+ → SW_12V+
- 12V_OUT− → GND BUS

Capacitor before/at 12V out (for motor noise)

- C12V_BULK: 1000µF–2200µF electrolytic (≥25V) across SW_12V+ ↔ GND BUS, placed near the 12V output connector

## Battery Capacity Indicator (after switch, before converters)

(So it turns off with the robot and reads the switched battery voltage)

- Indicator + / V → SW_12V+
- Indicator GND → GND BUS

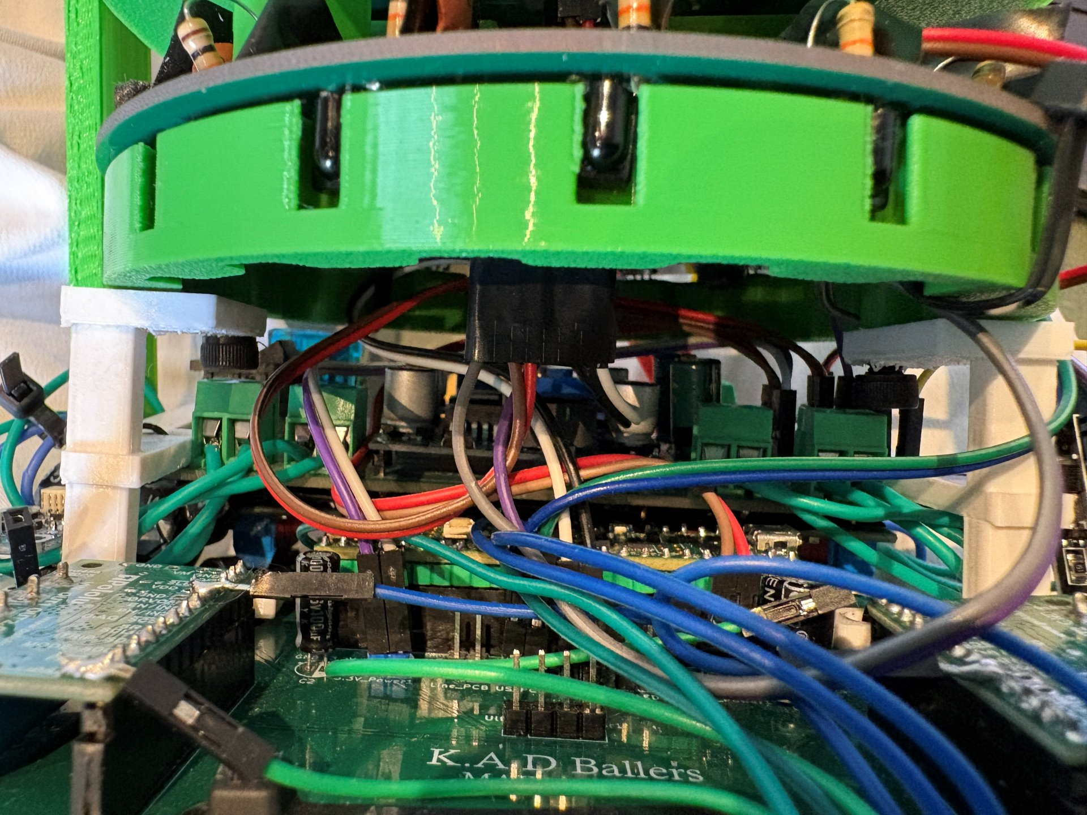
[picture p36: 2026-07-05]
RoboCup Internationals 2025-26/Docs/Images/Electronics/5V_3.3V_UART_Wiring.jpg

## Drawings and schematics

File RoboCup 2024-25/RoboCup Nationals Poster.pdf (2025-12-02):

# VVS BALLERS

## Attackers

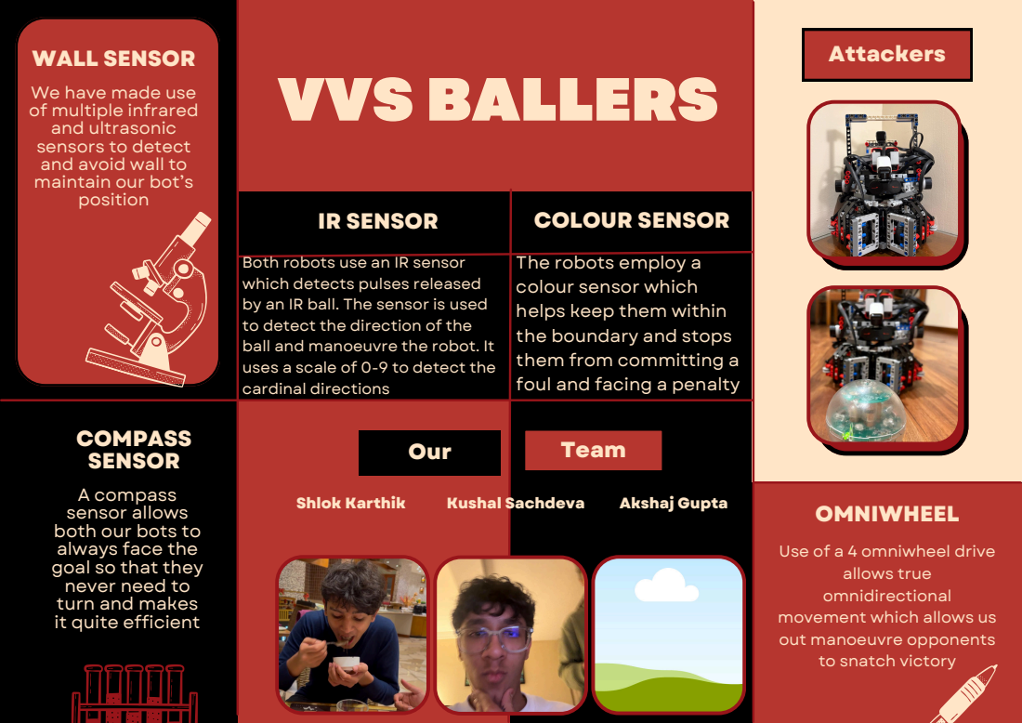
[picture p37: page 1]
Our; Team; IR SENSOR; COLOUR SENSOR; OMNIWHEEL; Shlok Karthik; Kushal Sachdeva; Akshaj Gupta

WALL SENSOR
We have made use
of multiple infrared
and ultrasonic
sensors to detect
and avoid wall to
maintain our bot’s
position

Both robots use an IR sensor
which detects pulses released
by an IR ball. The sensor is used
to detect the direction of the
ball and manoeuvre the robot. It
uses a scale of 0-9 to detect the
cardinal directions

The robots employ a
colour sensor which
helps keep them within
the boundary and stops
them from committing a
foul and facing a penalty

COMPASS
SENSOR
A compass
sensor allows
both our bots to
always face the
goal so that they
never need to
turn and makes
it quite efficient

Use of a 4 omniwheel drive

allows true
omnidirectional
movement which allows us
out manoeuvre opponents
to snatch victory

## Defence The team

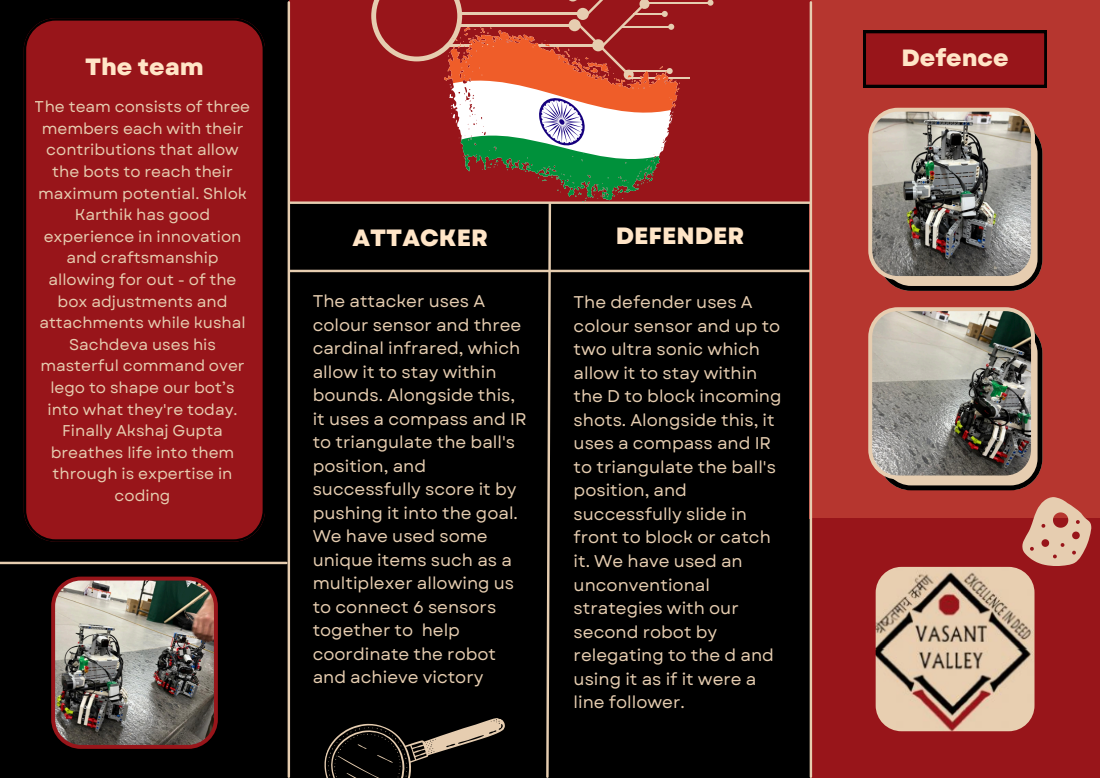
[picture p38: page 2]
coding; ATTACKER; DEFENDER

The team consists of three
members each with their
contributions that allow
the bots to reach their
maximum potential. Shlok
Karthik has good
experience in innovation
and craftsmanship
allowing for out - of the
box adjustments and
attachments while kushal
Sachdeva uses his
masterful command over
lego to shape our bot’s
into what they're today.
Finally Akshaj Gupta
breathes life into them
through is expertise in

The attacker uses A
colour sensor and three
cardinal infrared, which
allow it to stay within
bounds. Alongside this,
it uses a compass and IR
to triangulate the ball's
position, and
successfully score it by
pushing it into the goal.
We have used some
unique items such as a
multiplexer allowing us
to connect 6 sensors
together to help
coordinate the robot
and achieve victory

The defender uses A
colour sensor and up to
two ultra sonic which
the D to block incoming
shots. Alongside this, it
uses a compass and IR
successfully slide in
front to block or catch
it. We have used an
unconventional
strategies with our
second robot by
relegating to the d and
using it as if it were a
line follower.

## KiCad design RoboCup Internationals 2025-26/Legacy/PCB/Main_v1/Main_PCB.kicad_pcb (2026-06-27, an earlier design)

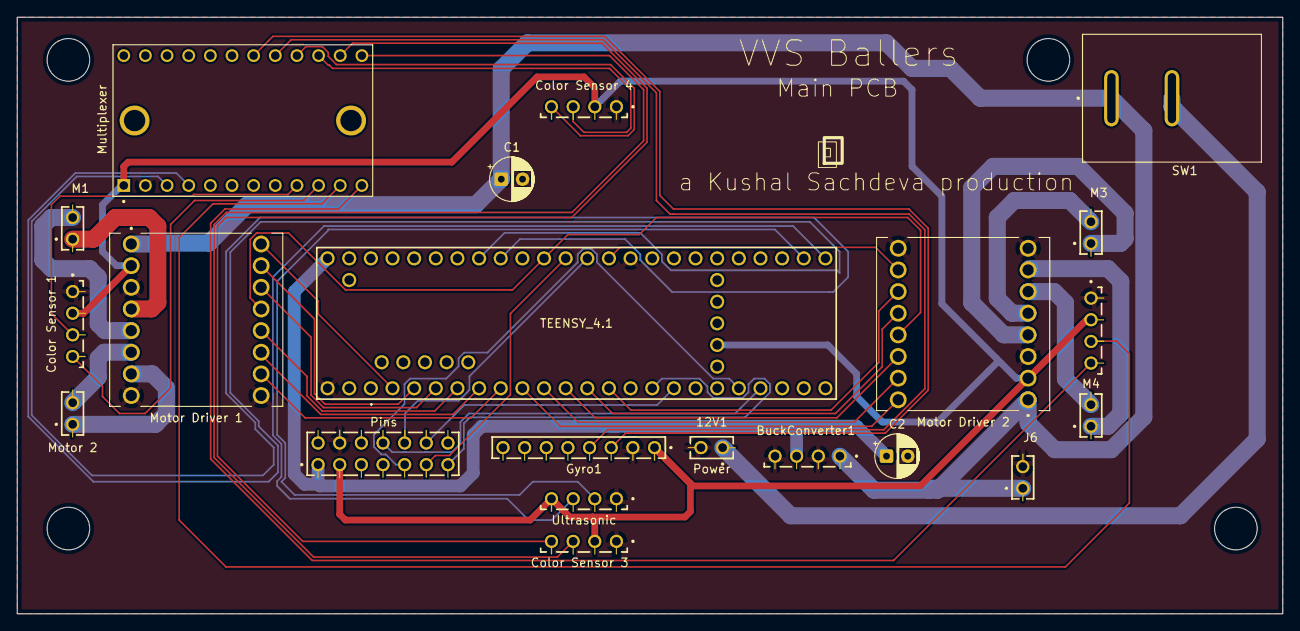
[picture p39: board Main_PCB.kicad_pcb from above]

Board: 2 copper layers, 148.5 x 70.0 mm, 21 parts (0 on the bottom side), 46 nets.

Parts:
12V1: Power; SAMTEC_MTLW-101-06-S-D-105
BuckConverter1: 12V to 5V; SAMTEC_MTLW-104-X-X-S-X
C1, C2: C; CP_Radial_D5.0mm_P2.50mm
Gyro1: Gyro; SAMTEC_MTLW-108-07-S-S-250
IC1: TEENSY_4.1; TEENSY41
J1: Color Sensor 1; SAMTEC_MTLW-104-X-X-S-X
J2: Color Sensor 2; SAMTEC_MTLW-104-X-X-S-X
J3: Color Sensor 3; SAMTEC_MTLW-104-X-X-S-X
J4: Color Sensor 4; SAMTEC_MTLW-104-X-X-S-X
J5: Ultrasonic; SAMTEC_MTLW-104-X-X-S-X
J6: Kicker; SAMTEC_MTLW-101-06-S-D-105
M1: Motor 1; SAMTEC_MTLW-101-06-S-D-105
M2: Motor 2; SAMTEC_MTLW-101-06-S-D-105
M3: Motor 3; SAMTEC_MTLW-101-06-S-D-105
M4: Motor 4; SAMTEC_MTLW-101-06-S-D-105
Motor Driver 1, Motor Driver 2: ROB-14450; MODULE_ROB-14450
Multiplexer: 2717; MODULE_2717
Pins: IR PCB; SAMTEC_MTLW-107-XX-X-D-XXX
SW1: SW_DIP_x01; SW_RF1-1A-DC-2-R-1

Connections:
GND: 12V1.02 (GND), BuckConverter1.02 (GND_IN), BuckConverter1.04 (GND_OUT), C1.2, C2.2, Gyro1.02 (GND), IC1.69 (GND_4), IC1.71 (GND_6), J1.01 (GND), J2.01 (GND), J3.01 (GND), J4.01 (GND), J5.01 (GND), J6.02 (GND), Motor Driver 1.3 (GND), Motor Driver 1.8 (GND), Motor Driver 1.9 (GND), Motor Driver 2.3 (GND), Motor Driver 2.8 (GND), Motor Driver 2.9 (GND), Multiplexer.2 (GND), Pins.04 (GND)
unnamed: 12V1.01 (12V), SW1.2
unnamed: BuckConverter1.03 (5V_OUT), C2.1, IC1.55 (VIN_(3.6_TO_5.5_VOLTS)), Pins.01 (5V)
unnamed: BuckConverter1.01 (12V_IN), C1.1, J6.01 (12V), Motor Driver 1.1 (VM), Motor Driver 2.1 (VM), SW1.1
unnamed: Gyro1.03 (SCL), Multiplexer.18 (SCL4)
unnamed: Gyro1.04 (SDA), Multiplexer.17 (SDA4)
unnamed: Gyro1.01 (VCC), IC1.44 (3.3V_2), J1.02 (VCC), J2.02 (VCC), J3.02 (VCC), J4.02 (VCC), J5.04 (Vcc), Motor Driver 1.2 (VCC), Motor Driver 2.2 (VCC), Multiplexer.1 (VIN), Pins.03 (3.3V)
unnamed: IC1.14 (A0), Pins.10 (RX_IR)
unnamed: IC1.15 (A1), Pins.11 (TX_IR)
unnamed: IC1.16 (A2), Motor Driver 1.13 (STBY), Motor Driver 2.13 (STBY)
unnamed: IC1.18 (A4), Multiplexer.3 (SDA)
unnamed: IC1.19 (A5), Multiplexer.4 (SCL)
unnamed: IC1.24 (A10), Pins.13 (SCL)
unnamed: IC1.25 (A11), Pins.12 (SDA)
unnamed: IC1.4 (BCLK2), Motor Driver 1.14 (AI1)
unnamed: IC1.10 (CS_1), Motor Driver 2.14 (AI1)
unnamed: IC1.5 (IN2), Motor Driver 1.12 (BI1)
unnamed: IC1.3 (LRCLK2), Motor Driver 1.15 (AI2)
unnamed: IC1.33 (MCLK2), J5.03 (Trig)
unnamed: IC1.12 (MISO), Motor Driver 2.11 (BI2)
unnamed: IC1.11 (MOSI), Motor Driver 2.12 (BI1)
unnamed: IC1.9 (OUT1C), Motor Driver 2.15 (AI2)
unnamed: IC1.6 (OUT1D), Motor Driver 1.11 (BI2)
unnamed: IC1.2 (OUT2), Motor Driver 1.16 (PWMA)
unnamed: IC1.7 (RX2), Motor Driver 1.10 (PWMB)
unnamed: IC1.28 (RX7), Pins.09 (TX_C)
unnamed: IC1.34 (RX8), J5.02 (Echo)
unnamed: IC1.13 (SCK), Motor Driver 2.10 (PWMB)
unnamed: IC1.8 (TX2), Motor Driver 2.16 (PWMA)
unnamed: IC1.29 (TX7), Pins.08 (RX_C)
unnamed: J1.04 (SCL), Multiplexer.10 (SCL0)
unnamed: J1.03 (SDA), Multiplexer.9 (SDA0)
unnamed: J2.04 (SCL), Multiplexer.12 (SCL1)
unnamed: J2.03 (SDA), Multiplexer.11 (SDA1)
unnamed: J3.04 (SCL), Multiplexer.14 (SCL2)
unnamed: J3.03 (SDA), Multiplexer.13 (SDA2)
unnamed: J4.04 (SCL), Multiplexer.16 (SCL3)
unnamed: J4.03 (SDA), Multiplexer.15 (SDA3)
unnamed: M1.01, Motor Driver 1.4 (A01)
unnamed: M1.02, Motor Driver 1.5 (A02)
unnamed: M2.01, Motor Driver 1.7 (B01)
unnamed: M2.02, Motor Driver 1.6 (B02)
unnamed: M3.01, Motor Driver 2.4 (A01)
unnamed: M3.02, Motor Driver 2.5 (A02)
unnamed: M4.01, Motor Driver 2.7 (B01)
unnamed: M4.02, Motor Driver 2.6 (B02)

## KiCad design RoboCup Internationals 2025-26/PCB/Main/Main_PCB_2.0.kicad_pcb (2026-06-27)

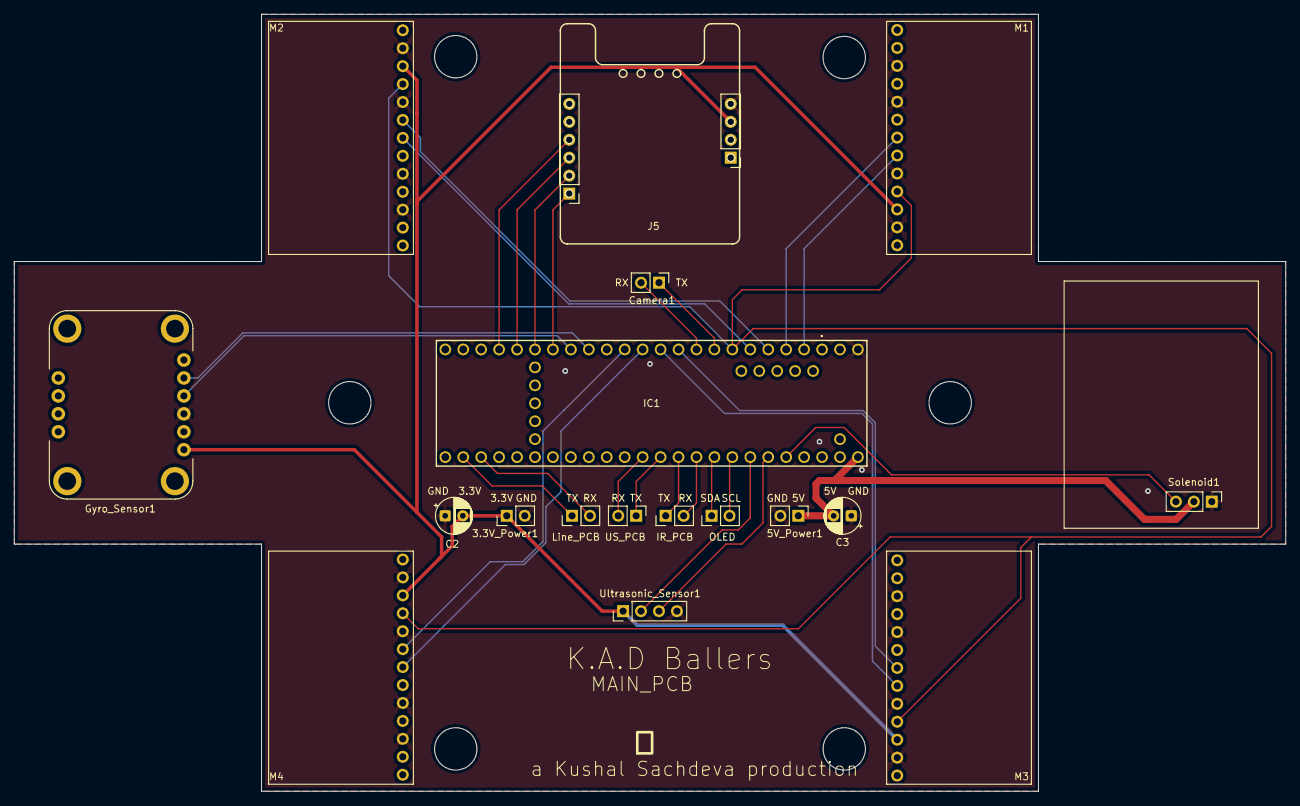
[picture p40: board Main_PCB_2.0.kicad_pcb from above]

Board: 2 copper layers, 180.0 x 110.0 mm, 19 parts (0 on the bottom side), 31 nets.

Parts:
3.3V_Power1, 5V_Power1: Conn_01x02; PinHeader_1x02_P2.54mm_Vertical
C2, C3: 104; CP_Radial_D5.0mm_P2.50mm
Camera1: Conn_01x02; PinHeader_1x02_P2.54mm_Vertical
Gyro_Sensor1: BNO055; MODULE_2472
IC1: TEENSY_4.1; TEENSY41
IR_PCB: Conn_01x02; PinHeader_1x02_P2.54mm_Vertical
J1, J2, J3, J4: Conn_01x13; PinHeader_1x13_P2.54mm_Vertical
J5: Conn_01x06; PinHeader_1x06_P2.54mm_Vertical
J6: Conn_01x04; PinHeader_1x04_P2.54mm_Vertical
Line_PCB: Conn_01x02; PinHeader_1x02_P2.54mm_Vertical
OLED: Conn_01x02; PinHeader_1x02_P2.54mm_Vertical
Solenoid1: Conn_01x03; PinHeader_1x03_P2.54mm_Vertical
US_PCB: Conn_01x02; PinHeader_1x02_P2.54mm_Vertical
Ultrasonic_Sensor1: Conn_01x04; PinHeader_1x04_P2.54mm_Vertical

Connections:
1_IN1: IC1.2 (OUT2), J1.6
1_IN2: IC1.3 (LRCLK2), J1.7
2_IN1: IC1.4 (BCLK2), J2.6
2_IN2: IC1.5 (IN2), J2.7
3_IN1: IC1.10 (CS_1), J3.6
3_IN2: IC1.9 (OUT1C), J3.7
4_IN1: IC1.12 (MISO), J4.6
4_IN2: IC1.11 (MOSI), J4.7
+3.3V: 3.3V_Power1.1, C2.2, Gyro_Sensor1.1 (VIN), J1.3, J2.3, J3.3, J4.3, J6.3, Ultrasonic_Sensor1.1
+5V: 5V_Power1.1, C3.2, IC1.55 (VIN_(3.6_TO_5.5_VOLTS)), Solenoid1.2
Echo: IC1.21 (A7), Ultrasonic_Sensor1.3
GND: 3.3V_Power1.2, 5V_Power1.2, C2.1, C3.1, Gyro_Sensor1.3 (GND), IC1.71 (GND_6), J1.2, J1.5, J1.9, J1.11, J2.2, J2.5, J2.9, J2.11, J3.2, J3.5, J3.9, J3.11, J4.2, J4.5, J4.9, J4.11, J6.4, Solenoid1.1, Ultrasonic_Sensor1.4
IN1: IC1.22 (A8), Solenoid1.3
OUT1: IC1.26 (A12), J5.1
OUT2: IC1.27 (A13), J5.2
RX_C: Camera1.2, IC1.8 (TX2)
RX_IR: IC1.17 (A3), IR_PCB.2
RX_L: IC1.35 (TX8), Line_PCB.2
RX_M: IC1.29 (TX7), J5.4
RX_U: IC1.14 (A0), US_PCB.2
SCL_G: Gyro_Sensor1.5 (SCL), IC1.24 (A10)
SCL_S: IC1.19 (A5), OLED.2
SDA_G: Gyro_Sensor1.4 (SDA), IC1.25 (A11)
SDA_S: IC1.18 (A4), OLED.1
SLEEP: IC1.6 (OUT1D), J1.4, J2.4, J3.4, J4.4
TX_C: Camera1.1, IC1.7 (RX2)
TX_IR: IC1.16 (A2), IR_PCB.1
TX_L: IC1.34 (RX8), Line_PCB.1
TX_M: IC1.28 (RX7), J5.3
TX_U: IC1.15 (A1), US_PCB.1
Trig: IC1.20 (A6), Ultrasonic_Sensor1.2

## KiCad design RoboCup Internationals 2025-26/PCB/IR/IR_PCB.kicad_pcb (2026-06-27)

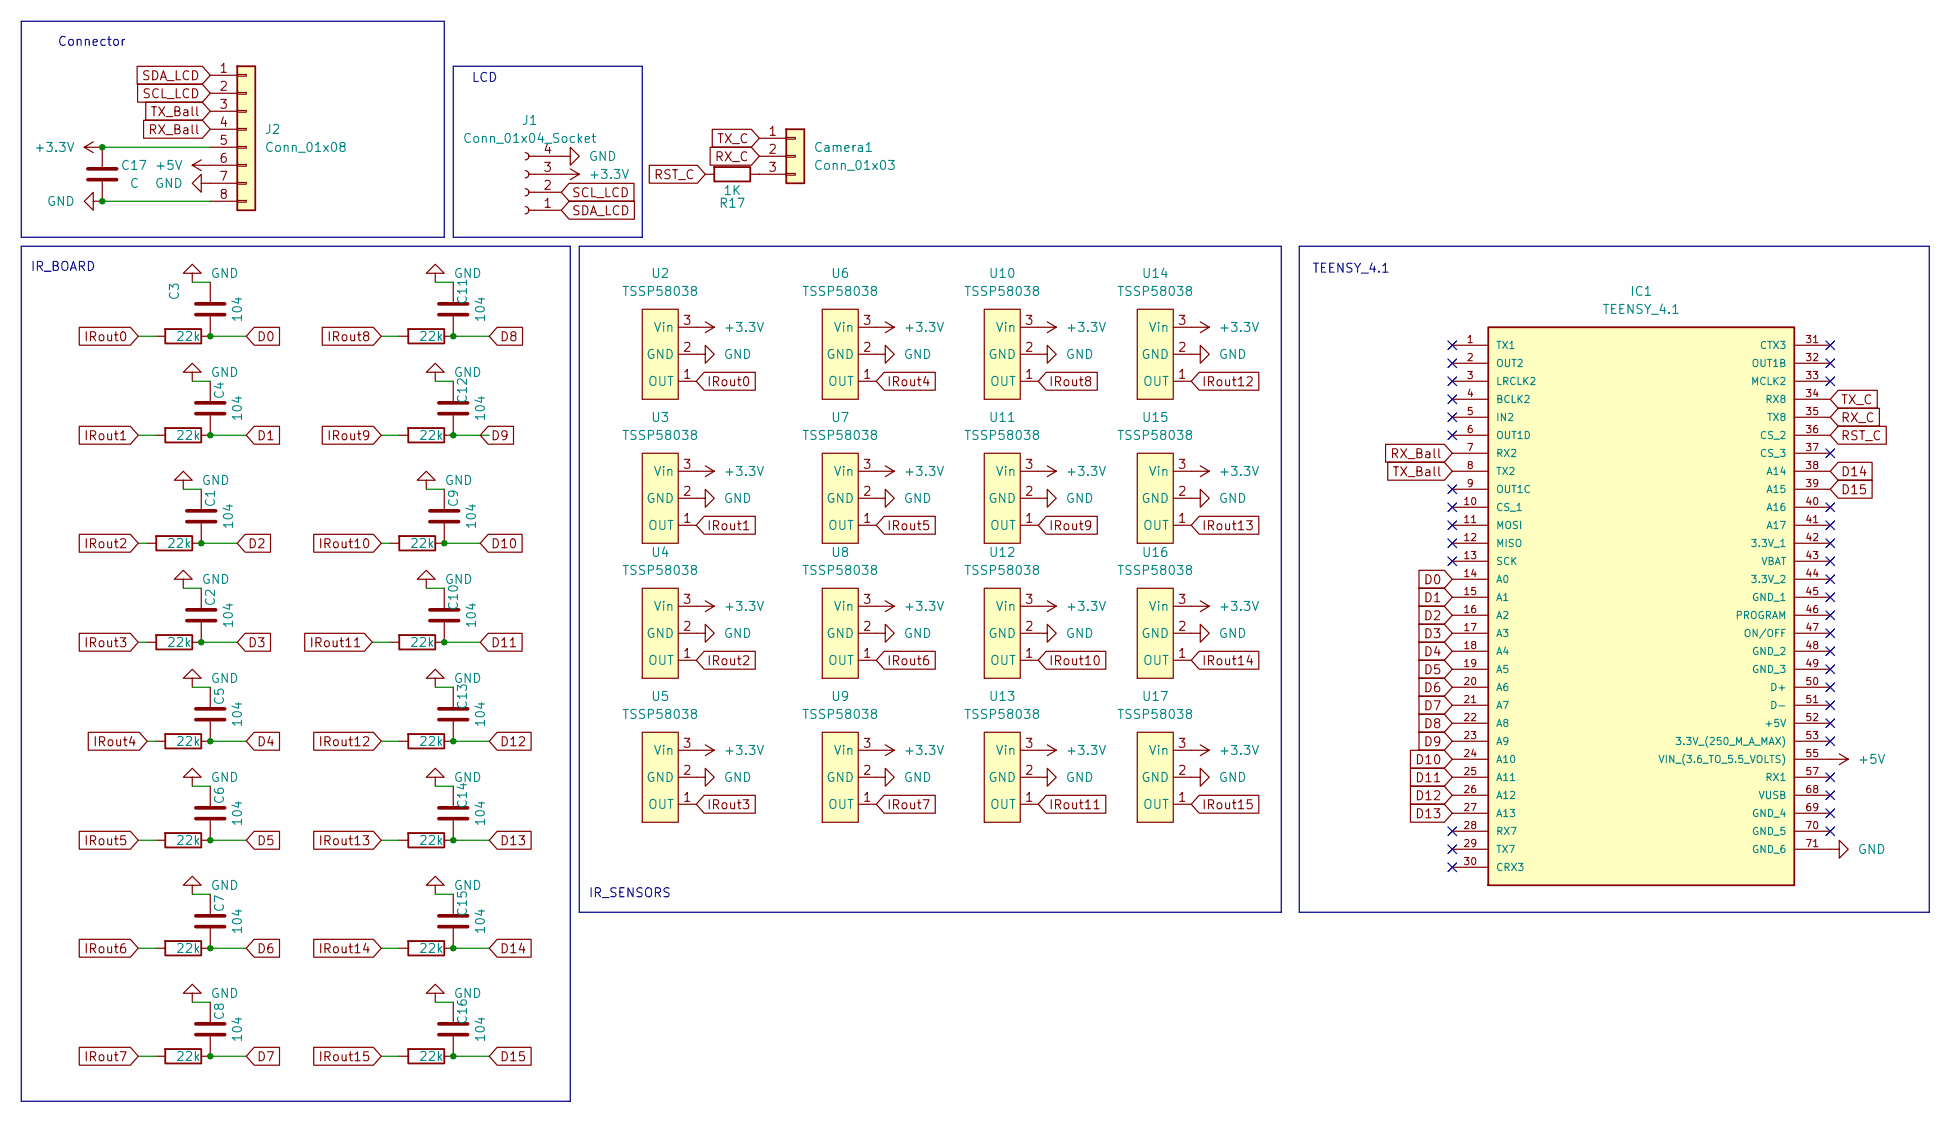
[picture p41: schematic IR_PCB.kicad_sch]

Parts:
C1, C2, C3, C4, C5, C6, C7, C8, C9, C10, C11, C12, C13, C14, C15, C16: 104; C_Disc_D5.0mm_W2.5mm_P2.50mm
C17: C; C_Disc_D5.0mm_W2.5mm_P2.50mm
Camera1: Conn_01x03; PinHeader_1x03_P2.54mm_Vertical
IC1: TEENSY_4.1; TEENSY41; Manufacturer_Part_Number TEENSY 4.1
J1: Conn_01x04_Socket; PinHeader_1x04_P2.54mm_Vertical
J2: Conn_01x08; PinHeader_1x08_P2.54mm_Vertical
R1, R2, R3, R4, R5, R6, R7, R8, R9, R10, R11, R12, R13, R14, R15, R16: 22k; R_Axial_DIN0204_L3.6mm_D1.6mm_P5.08mm_Vertical
R17: 1K; R_Axial_DIN0204_L3.6mm_D1.6mm_P5.08mm_Vertical
U2, U3, U4, U5, U6, U7, U8, U9, U10, U11, U12, U13, U14, U15, U16, U17: TSSP58038; PinHeader_1x03_P2.54mm_Vertical

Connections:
+3.3V: C17.1, J1.3, J2.5, U2.3 (Vin), U3.3 (Vin), U4.3 (Vin), U5.3 (Vin), U6.3 (Vin), U7.3 (Vin), U8.3 (Vin), U9.3 (Vin), U10.3 (Vin), U11.3 (Vin), U12.3 (Vin), U13.3 (Vin), U14.3 (Vin), U15.3 (Vin), U16.3 (Vin), U17.3 (Vin)
+5V: IC1.55 (VIN_(3.6_TO_5.5_VOLTS)), J2.6
D0: C3.1, IC1.14 (A0), R3.1
D1: C4.1, IC1.15 (A1), R4.1
D2: C1.1, IC1.16 (A2), R1.1
D3: C2.1, IC1.17 (A3), R2.1
D4: C5.1, IC1.18 (A4), R5.1
D5: C6.1, IC1.19 (A5), R6.1
D6: C7.1, IC1.20 (A6), R7.1
D7: C8.1, IC1.21 (A7), R8.1
D8: C11.1, IC1.22 (A8), R11.1
D9: C12.1, IC1.23 (A9), R12.1
D10: C9.1, IC1.24 (A10), R9.1
D11: C10.1, IC1.25 (A11), R10.1
D12: C13.1, IC1.26 (A12), R13.1
D13: C14.1, IC1.27 (A13), R14.1
D14: C15.1, IC1.38 (A14), R15.1
D15: C16.1, IC1.39 (A15), R16.1
GND: C1.2, C2.2, C3.2, C4.2, C5.2, C6.2, C7.2, C8.2, C9.2, C10.2, C11.2, C12.2, C13.2, C14.2, C15.2, C16.2, C17.2, IC1.71 (GND_6), J1.4, J2.7, J2.8, U2.2 (GND), U3.2 (GND), U4.2 (GND), U5.2 (GND), U6.2 (GND), U7.2 (GND), U8.2 (GND), U9.2 (GND), U10.2 (GND), U11.2 (GND), U12.2 (GND), U13.2 (GND), U14.2 (GND), U15.2 (GND), U16.2 (GND), U17.2 (GND)
IRout0: R3.2, U2.1 (OUT)
IRout1: R4.2, U3.1 (OUT)
IRout2: R1.2, U4.1 (OUT)
IRout3: R2.2, U5.1 (OUT)
IRout4: R5.2, U6.1 (OUT)
IRout5: R6.2, U7.1 (OUT)
IRout6: R7.2, U8.1 (OUT)
IRout7: R8.2, U9.1 (OUT)
IRout8: R11.2, U10.1 (OUT)
IRout9: R12.2, U11.1 (OUT)
IRout10: R9.2, U12.1 (OUT)
IRout11: R10.2, U13.1 (OUT)
IRout12: R13.2, U14.1 (OUT)
IRout13: R14.2, U15.1 (OUT)
IRout14: R15.2, U16.1 (OUT)
IRout15: R16.2, U17.1 (OUT)
unnamed 35: Camera1.3, R17.1; also elsewhere on the board
RST_C: IC1.36 (CS_2), R17.2; also elsewhere on the board
RX_Ball: IC1.7 (RX2), J2.4
RX_C: Camera1.2, IC1.35 (TX8)
SCL_LCD: J1.2, J2.2
SDA_LCD: J1.1, J2.1
TX_Ball: IC1.8 (TX2), J2.3
TX_C: Camera1.1, IC1.34 (RX8)

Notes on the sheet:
LCD
TEENSY_4.1
IR_BOARD
Connector
IR_SENSORS

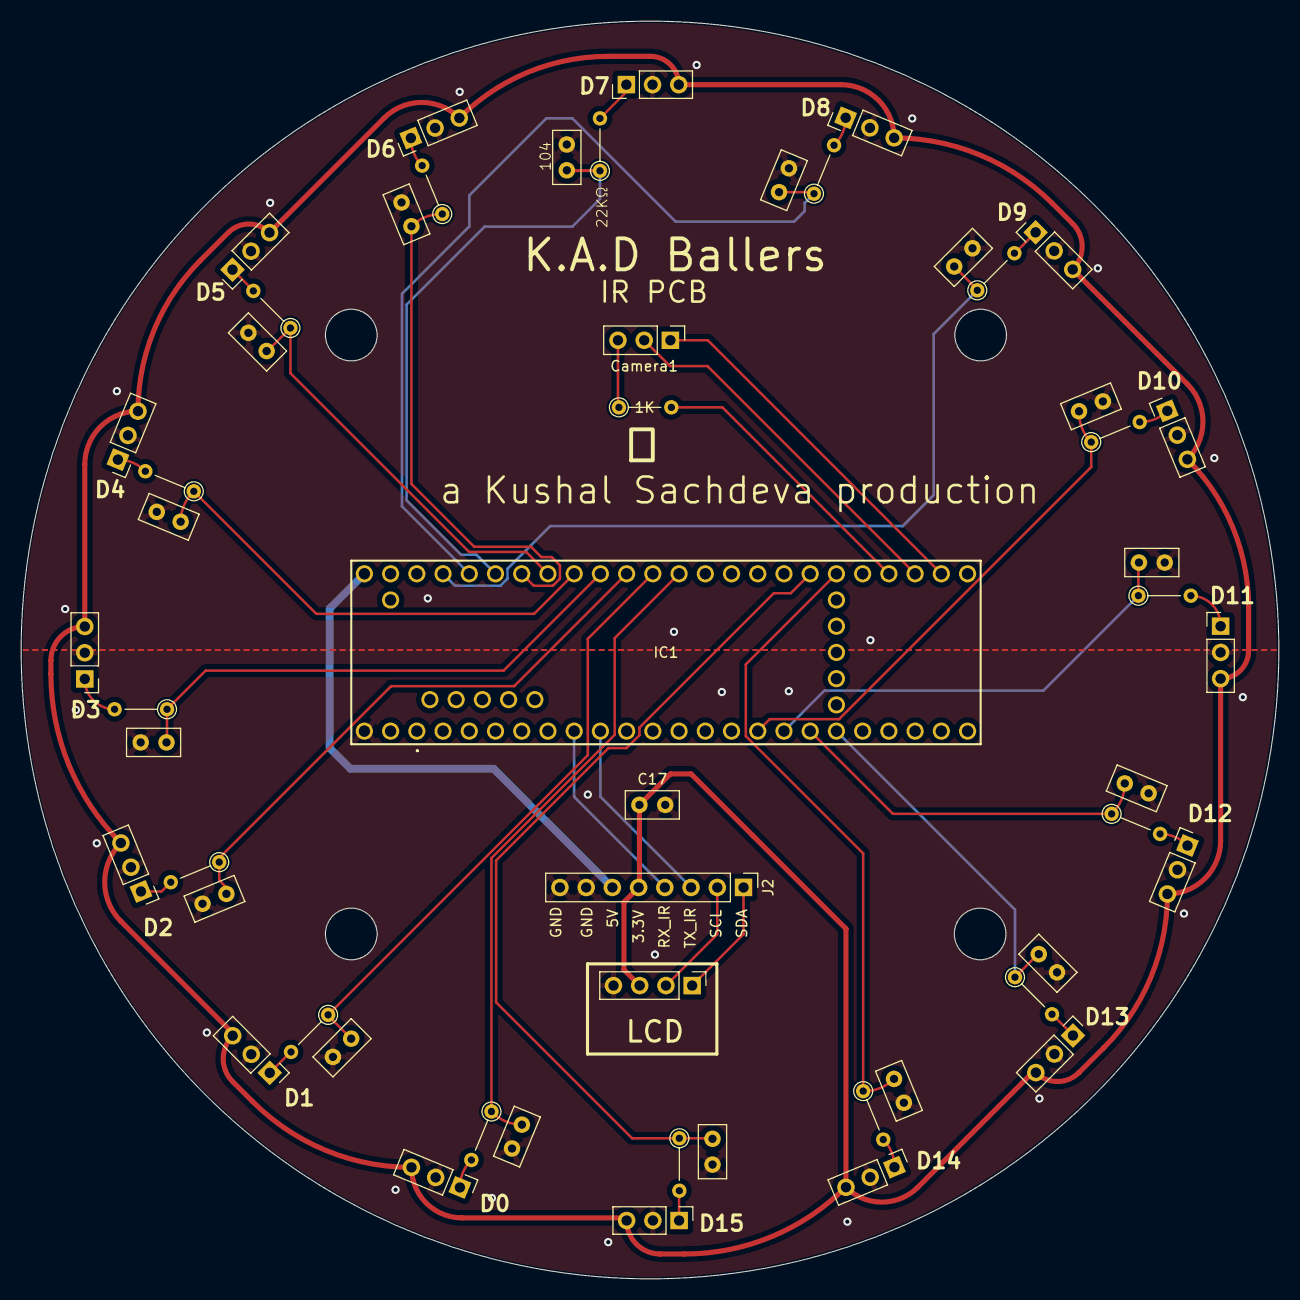
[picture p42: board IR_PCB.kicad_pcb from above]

Board: 2 copper layers, 121.8 x 121.8 mm, 54 parts (0 on the bottom side), 43 nets.

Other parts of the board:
1K: 1K; R_Axial_DIN0204_L3.6mm_D1.6mm_P5.08mm_Vertical

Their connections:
unnamed 35: 1K.1; also elsewhere on the board
RST_C: 1K.2; also elsewhere on the board

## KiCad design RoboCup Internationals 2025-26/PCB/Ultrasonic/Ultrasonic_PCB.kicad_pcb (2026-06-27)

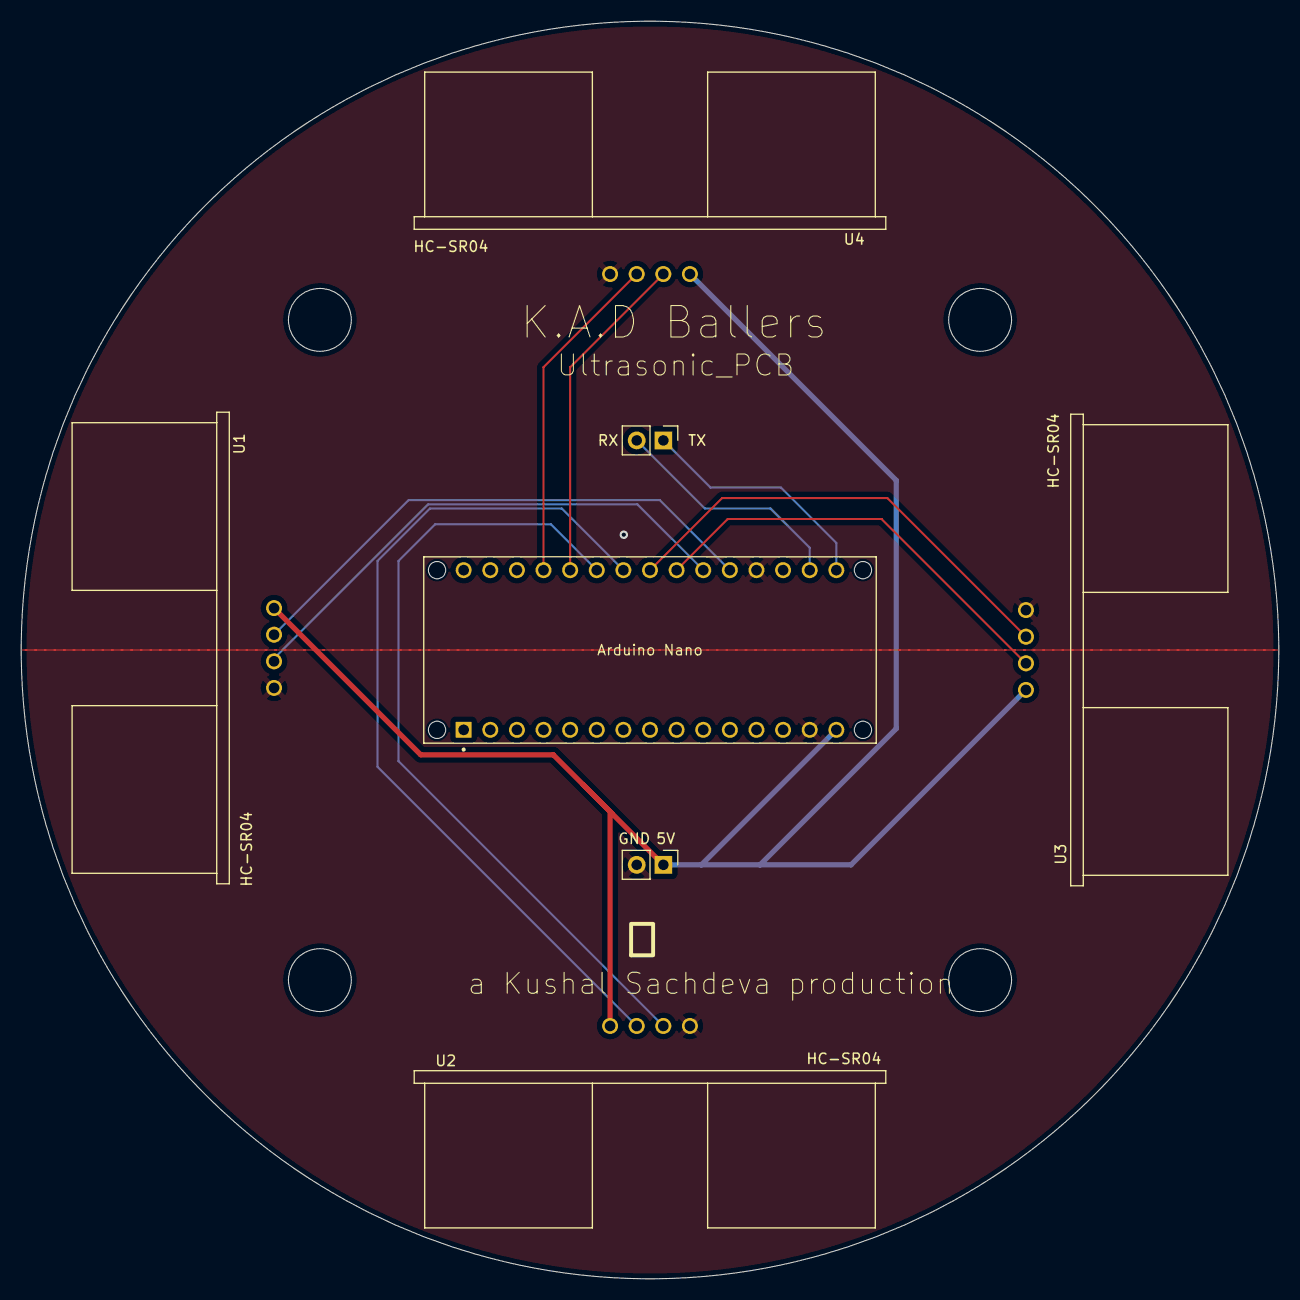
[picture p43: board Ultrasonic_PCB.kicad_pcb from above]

Board: 2 copper layers, 120.0 x 120.0 mm, 7 parts (0 on the bottom side), 12 nets.

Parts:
5V: Conn_01x02; PinHeader_1x02_P2.54mm_Vertical
Arduino Nano: ABX00028; MODULE_ABX00028
RX: Conn_01x02; PinHeader_1x02_P2.54mm_Vertical
U1, U2, U3, U4: HC-SR04; XCVR_HC-SR04

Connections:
GND: 5V.2, Arduino Nano.14 (GND), Arduino Nano.19 (GND), U1.4 (GND), U2.4 (GND), U3.4 (GND), U4.4 (GND)
unnamed: 5V.1, Arduino Nano.15 (VIN), U1.1 (VCC), U2.1 (VCC), U3.1 (VCC), U4.1 (VCC)
unnamed: Arduino Nano.16 (TX), RX.1
unnamed: Arduino Nano.17 (RX), RX.2
unnamed: Arduino Nano.20 (D2), U1.2 (TRIG)
unnamed: Arduino Nano.21 (D3/PWM), U1.3 (ECHO)
unnamed: Arduino Nano.22 (D4), U3.2 (TRIG)
unnamed: Arduino Nano.23 (D5/PWM), U3.3 (ECHO)
unnamed: Arduino Nano.24 (D6/PWM), U2.2 (TRIG)
unnamed: Arduino Nano.25 (D7), U2.3 (ECHO)
unnamed: Arduino Nano.26 (D8), U4.2 (TRIG)
unnamed: Arduino Nano.27 (D9/PWM), U4.3 (ECHO)

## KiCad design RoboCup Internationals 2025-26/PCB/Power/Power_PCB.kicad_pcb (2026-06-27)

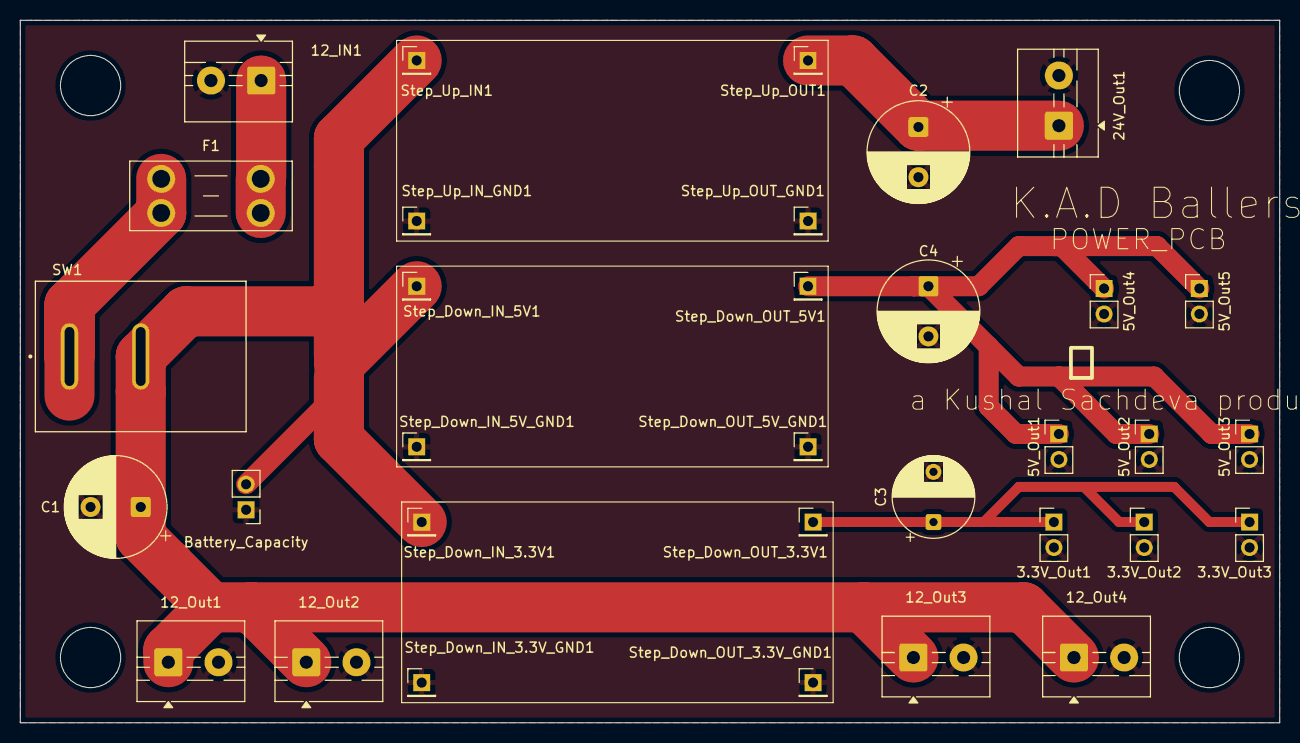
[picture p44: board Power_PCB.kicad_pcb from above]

Board: 2 copper layers, 125.5 x 70.0 mm, 33 parts (0 on the bottom side), 7 nets.

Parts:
3.3V_Out1, 3.3V_Out2, 3.3V_Out3: Conn_01x02; PinHeader_1x02_P2.54mm_Vertical
5V_Out1: IR; PinHeader_1x02_P2.54mm_Vertical
5V_Out2: Line; PinHeader_1x02_P2.54mm_Vertical
5V_Out3: Main_PCB; PinHeader_1x02_P2.54mm_Vertical
5V_Out4: US_PCB; PinHeader_1x02_P2.54mm_Vertical
5V_Out5: Camera; PinHeader_1x02_P2.54mm_Vertical
12_IN1, 12_Out1, 12_Out2, 12_Out3, 12_Out4: Screw_Terminal_01x02; TerminalBlock_MaiXu_MX126-5.0-02P_1x02_P5.00mm
24V_Out1: Conn_01x02; TerminalBlock_MaiXu_MX126-5.0-02P_1x02_P5.00mm
Battery_Capacity: Conn_01x02; PinHeader_1x02_P2.54mm_Vertical
C1, C2, C4: C; CP_Radial_D10.0mm_P5.00mm
C3: C; CP_Radial_D8.0mm_P5.00mm
F1: Fuse; Fuseholder_Blade_Mini_Keystone_3568
SW1: SW_DIP_x01; SW_RF1-1A-DC-2-R-1
Step_Down_IN_3.3V1, Step_Down_IN_3.3V_GND1, Step_Down_IN_5V1, Step_Down_IN_5V_GND1: Conn_01x01; PinHeader_1x01_P2.54mm_Vertical
Step_Down_OUT_3.3V1, Step_Down_OUT_3.3V_GND1, Step_Down_OUT_5V1, Step_Down_OUT_5V_GND1: Conn_01x01; PinHeader_1x01_P2.54mm_Vertical
Step_Up_IN1: Conn_01x01; PinHeader_1x01_P2.54mm_Vertical
Step_Up_IN_GND1: Conn_01x01; PinHeader_1x01_P2.54mm_Vertical
Step_Up_OUT1: Conn_01x01; PinHeader_1x01_P2.54mm_Vertical
Step_Up_OUT_GND1: Conn_01x01; PinHeader_1x01_P2.54mm_Vertical

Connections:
GND: 3.3V_Out1.2, 3.3V_Out2.2, 3.3V_Out3.2, 5V_Out1.2, 5V_Out2.2, 5V_Out3.2, 5V_Out4.2, 5V_Out5.2, 12_IN1.2, 12_Out1.2, 12_Out2.2, 12_Out3.2, 12_Out4.2, 24V_Out1.2, Battery_Capacity.1, C1.2, C2.2, C3.2, C4.2, Step_Down_IN_3.3V_GND1.1, Step_Down_IN_5V_GND1.1, Step_Down_OUT_3.3V_GND1.1, Step_Down_OUT_5V_GND1.1, Step_Up_IN_GND1.1, Step_Up_OUT_GND1.1
unnamed: 3.3V_Out1.1, 3.3V_Out2.1, 3.3V_Out3.1, C3.1, Step_Down_OUT_3.3V1.1
unnamed: 5V_Out1.1, 5V_Out2.1, 5V_Out3.1, 5V_Out4.1, 5V_Out5.1, C4.1, Step_Down_OUT_5V1.1
unnamed: 12_IN1.1, F1.2
unnamed: 12_Out1.1, 12_Out2.1, 12_Out3.1, 12_Out4.1, Battery_Capacity.2, C1.1, SW1.2, Step_Down_IN_3.3V1.1, Step_Down_IN_5V1.1, Step_Up_IN1.1
unnamed: 24V_Out1.1, C2.1, Step_Up_OUT1.1
unnamed: F1.1, SW1.1

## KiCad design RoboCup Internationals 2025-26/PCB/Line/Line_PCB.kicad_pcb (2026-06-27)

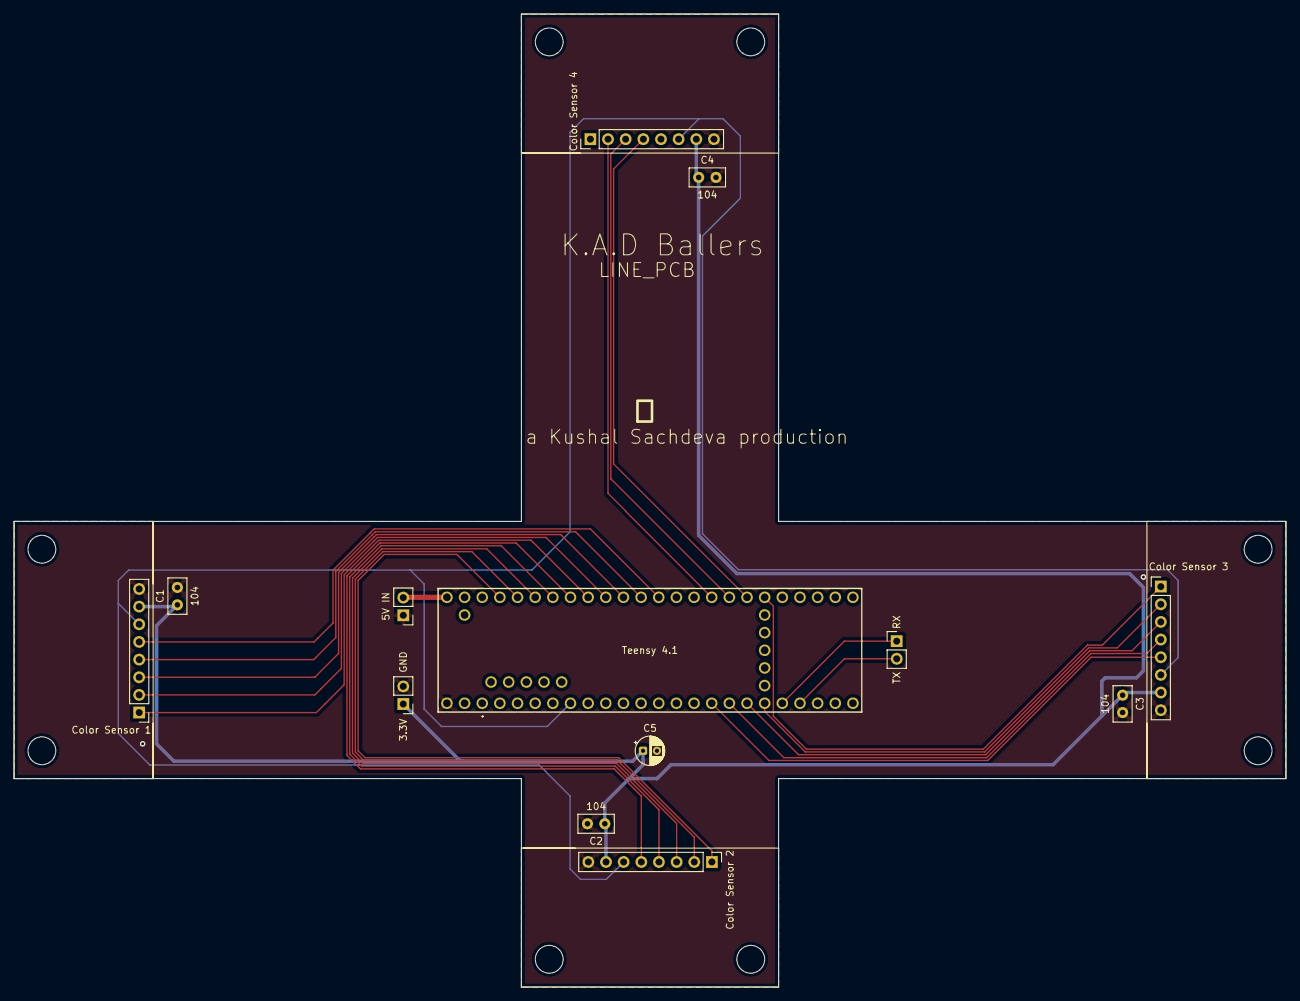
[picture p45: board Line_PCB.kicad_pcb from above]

Board: 2 copper layers, 183.0 x 140.0 mm, 13 parts (0 on the bottom side), 24 nets.

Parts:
5V IN: Conn_01x02; PinHeader_1x02_P2.54mm_Vertical
C1, C2, C3, C4: 104; C_Disc_D5.0mm_W2.5mm_P2.50mm
C5: 104; CP_Radial_D4.0mm_P2.00mm
Color Sensor 1, Color Sensor 2, Color Sensor 3, Color Sensor 4: Conn_01x08; PinHeader_1x08_P2.54mm_Vertical
J5, J6: Conn_01x02; PinHeader_1x02_P2.54mm_Vertical
Teensy 4.1: TEENSY_4.1; TEENSY41

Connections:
+3.3V: C1.1, C2.1, C3.1, C4.1, C5.1, Color Sensor 1.7, Color Sensor 2.7, Color Sensor 3.7, Color Sensor 4.7, J5.1
+5V: 5V IN.2, Teensy 4.1.55 (VIN_(3.6_TO_5.5_VOLTS))
GND: 5V IN.1, C1.2, C2.2, C3.2, C4.2, C5.2, Color Sensor 1.8, Color Sensor 2.8, Color Sensor 3.8, Color Sensor 4.8, J5.2, Teensy 4.1.71 (GND_6)
Odd: Color Sensor 1.6, Color Sensor 2.6, Color Sensor 3.6, Color Sensor 4.6, Teensy 4.1.6 (OUT1D)
Out1: Color Sensor 1.5, Teensy 4.1.14 (A0)
Out2: Color Sensor 1.4, Teensy 4.1.15 (A1)
Out3: Color Sensor 1.3, Teensy 4.1.16 (A2)
Out4: Color Sensor 1.2, Teensy 4.1.17 (A3)
Out5: Color Sensor 1.1, Teensy 4.1.18 (A4)
Out6: Color Sensor 2.5, Teensy 4.1.19 (A5)
Out7: Color Sensor 2.4, Teensy 4.1.20 (A6)
Out8: Color Sensor 2.3, Teensy 4.1.21 (A7)
Out9: Color Sensor 2.2, Teensy 4.1.22 (A8)
Out10: Color Sensor 2.1, Teensy 4.1.23 (A9)
Out11: Color Sensor 3.5, Teensy 4.1.24 (A10)
Out12: Color Sensor 3.4, Teensy 4.1.25 (A11)
Out13: Color Sensor 3.3, Teensy 4.1.26 (A12)
Out14: Color Sensor 3.2, Teensy 4.1.27 (A13)
Out15: Color Sensor 3.1, Teensy 4.1.38 (A14)
Out16: Color Sensor 4.4, Teensy 4.1.39 (A15)
Out17: Color Sensor 4.3, Teensy 4.1.40 (A16)
Out18: Color Sensor 4.2, Teensy 4.1.41 (A17)
RX_Out: J6.1, Teensy 4.1.28 (RX7)
TX_Out: J6.2, Teensy 4.1.29 (TX7)

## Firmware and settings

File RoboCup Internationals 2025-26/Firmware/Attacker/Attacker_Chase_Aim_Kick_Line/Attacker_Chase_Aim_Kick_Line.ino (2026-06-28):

/*
  ============================================================================
  ATTACKER MAIN  -  IR CHASE + FUSED LINE/US BOUNDARY ESCAPE + CAMERA AIM + KICK
  Teensy 4.1 main board  |  RoboCup Junior Lightweight attacker
  ----------------------------------------------------------------------------
  Sensor links and behaviour:
   - Line PCB receiver on Serial8 (RX8 = pin 34 <- Line PCB TX7/pin 29). Parses the
       Line Teensy's 9-byte packet with the SAME non-blocking poll + CRC-8 + seq
       + stale-timeout pattern as the ultrasonic link. Decodes 4 per-board line
       flags (QTR1=RIGHT, QTR2=FRONT, QTR3=LEFT, QTR4=BACK).

   - Fused field-boundary escape. A side is a boundary only when BOTH agree:
            front : US_FRONT < 300 mm AND QTR2 sees line  -> flee BACK
            right : US_RIGHT < 300 mm AND QTR1 sees line  -> flee LEFT
            left  : US_LEFT  < 300 mm AND QTR3 sees line  -> flee RIGHT
            back  : US_BACK  < 300 mm AND QTR4 sees line  -> flee FRONT
       If more than one qualifies, flee the CLOSEST (smallest US distance). No
       escape fires if EITHER the US link OR the Line link is stale.
       Optional: #define KEEP_OBSTACLE_FALLBACK 1 to restore plain US obstacle
       dodging at LOWER priority than the boundary escape (see that block).

   - Camera aim: on ball capture the chassis turns in place on the BNO055 PID to
       put the open goal-corner dead ahead, then kicks.
         Camera wiring (OpenMV H7 -> Teensy 4.1):
           OpenMV P4 (TX) ---> Teensy pin 7  (RX2)   <-- data line, REQUIRED
           OpenMV P5 (RX) <--- Teensy pin 8  (TX2)   optional, unused
           OpenMV GND     ---- Teensy GND            REQUIRED (common ground)
           OpenMV VIN     <--- Teensy 5V / VIN rail
   - Avoidance debounce: an offending side must persist AVOID_CONFIRM control
       passes before the robot flees.

  PRIORITY each control pass (highest first):
    1. HAVE BALL -> AIM open corner -> KICK
    2. BOUNDARY ESCAPE (line + US agree, debounced)   [+ optional US-only dodge]
    3. CHASE the ball
    4. IDLE

  Wiring (from the Main PCB doc):
    SLEEP -> 6 ;  M1: 2,3 ;  M2: 4,5 ;  M3: 9,10 ;  M4: 11,12
    BNO055 on Wire2: SDA=25, SCL=24, VIN=3.3V, addr 0x28, IMUPLUS
    IR UART       : Serial4 (RX4 = pin 16 <- IR board TX)
    Ultrasonic PCB: Serial3 (RX3 = pin 15 <- US board TX, TX3 = pin 14)
    Line PCB      : Serial8 (RX8 = pin 34 <- Line PCB TX7/pin 29)
    Goal camera   : Serial2 (RX2 = pin 7  <- OpenMV P4/TX ; common GND REQUIRED)
    Capture HC-SR04: TRIG = pin 20, ECHO = pin 21
    Kicker relay  : IN1 = pin 22 (ACTIVE-HIGH on this board)

  Arduino IDE target: Tools -> Board: Teensy 4.1 ;  USB Type: Serial.
  ============================================================================
*/

#include <Wire.h>
#include <Adafruit_Sensor.h>
#include <Adafruit_BNO055.h>
#include <utility/imumaths.h>

// ----------------------------- Motor pins -----------------------------------
const int SLEEP_PIN = 6;
const int M1_EN = 2,  M1_DIR = 3;
const int M2_EN = 4,  M2_DIR = 5;
const int M3_EN = 10, M3_DIR = 9;
const int M4_EN = 12, M4_DIR = 11;

// Rotation mix (spin in place) - identical to the working forward/hold sketch.
const int turnSign[4] = { -1, +1, -1, +1 };

// ------------------------ Movement sign patterns ----------------------------
// Motor command sign for each [sector][motor 1..4], multiplied by drive speed.
//   FORWARD : all negative   BACK : opposite   LEFT : (-+ + -)   RIGHT : opp LEFT
//  If left/right spin instead of strafing, swap to the STRAFE_FIX block below.
enum Sector { S_FWD = 0, S_RIGHT = 1, S_LEFT = 2, S_BACK = 3, S_NONE = 4 };

const int moveSign[4][4] = {
  /* S_FWD   */ { -1, -1, -1, -1 },
  /* S_RIGHT */ { +1, -1, -1, +1 },   // opposite of LEFT
  /* S_LEFT  */ { -1, +1, +1, -1 },
  /* S_BACK  */ { +1, +1, +1, +1 },
};

// // ---- STRAFE_FIX (use if left/right spin instead of sliding sideways) ----
// const int moveSign[4][4] = {
//   /* S_FWD   */ { -1, -1, -1, -1 },
//   /* S_RIGHT */ { -1, +1, +1, -1 },
//   /* S_LEFT  */ { +1, -1, -1, +1 },
//   /* S_BACK  */ { +1, +1, +1, +1 },
// };

// Top-level behaviour selected each control pass (debug + dispatch).
enum TopState { ST_IDLE = 0, ST_CHASE = 1, ST_AVOID = 2, ST_AIM = 3 };

// ============================================================================
//  Camera aim + kicker tunables.
// ============================================================================
// ---- Goal camera (OpenMV H7 on Serial2) ----
#define   CAM_BAUD      115200
const unsigned long CAM_STALE_MS = 200;     // no valid cam frame this long -> "goal not seen"
const int KICK_AIM_TOL_DEG = 5;             // fire only when |openCornerBear| <= this (deg)

// ---- Camera + IR ball fusion (the IR ring stays PRIMARY) ----
// The camera also reports the orange ball (flags bit3 + ballBearing + ballDist). The
// IR ring is the primary ball sensor; the camera ball is a SHORT-RANGE cross-check and
// a fallback when the IR ring drops the ball. The camera bearing is "+right, 0=front";
// the IR `dir` uses this robot's reversed convention (a ball AHEAD reads near +/-180),
// so the camera ball is mapped into that convention before it is compared/used.
#define   USE_CAM_BALL_FUSION    1          // 0 = ignore the camera ball (IR-only chase)
const uint8_t CAM_BALL_NEAR_CM      = 25;   // camera ball "short range" gate (cm)
const int     CAM_BALL_DISAGREE_DEG = 35;   // |camBall - IR| over this at short range -> trust camera

// ---- Aim behaviour ----
// AIM_TURN_SIGN: BNO055 yaw direction vs the camera's "+ = right". CANNOT be
// assumed. We command heading = (heading + AIM_TURN_SIGN*openCornerBear). If a
// goal waved to the robot's RIGHT makes it turn LEFT (spins away), flip to -1.0.
// >>> BENCH-VERIFY: wave the goal to the robot's right; it must turn RIGHT.
const float AIM_TURN_SIGN = +1.0;
// Small forward bias while aiming, to keep the ball pinned. 0 = pure spin in
// place (DEFAULT, and the only value at which suppressing avoidance during aim
// is guaranteed wall-safe). Raise (e.g. 40) only with a spotter.
const int AIM_FORWARD_BIAS = 0;
// 1 = match mode: kick ONLY when the goal is seen AND the open corner is aligned
//     (this is "the turn thing").
// 0 = bench/kicker-test mode: kick on ball capture alone (no camera needed),
//     to test the kicker in isolation.
#define   REQUIRE_GOAL_TO_KICK  1

// ---- Avoidance debounce: reject single spurious frames ----
const int AVOID_CONFIRM = 3;                // offending side must persist this many
                                            // control passes before the robot flees

// ------------------------------- Tuning (original) --------------------------
const int   DRIVE_SPEED   = 250;   // base wheel speed while chasing the ball
const int   AVOID_SPEED   = 250;   // wheel speed while fleeing a boundary/obstacle

#define     HOLD_HEADING  1        // 1 = stay facing the setpoint, 0 = off
#define     IR_DIR_INVERT 0        // set 1 if a ball on the RIGHT reads NEGATIVE

// ---- FUSED BOUNDARY ESCAPE distance (replaces the old US_AVOID_MM = 200) ----
// A side counts as the FIELD BOUNDARY only when its ultrasonic is under this AND
// that board's QTR sees the white line (see boundaryEscapeSector below).
const uint16_t BOUNDARY_MM = 300;

float       Kp = 6.0, Ki = 0.0, Kd = 0.5;
const float MAX_CORRECTION = 200;
float       K_SIGN = -1.0;

const unsigned long LOOP_MS       = 10;    // 100 Hz control update
const unsigned long IR_TIMEOUT_MS = 250;   // no IR frame this long -> no ball

// ----------------- Capture sensor + solenoid kicker -------------------------
// HC-SR04 in the capture mouth + relay-driven solenoid. After CONFIRM_SAMPLES
// consecutive in-range pings the ball is CAPTURED; the kicker then fires for
// KICK_MS (gated by the aim, see REQUIRE_GOAL_TO_KICK) and rests KICK_COOLDOWN_MS.
// A hard KICK_MAX_ON_MS guard force-releases the coil no matter what.
const int CAPTURE_TRIG = 20;
const int CAPTURE_ECHO = 21;
const int SOLENOID_PIN = 22;

#define   CAPTURE_BALL_MM   45       // ball "captured" when closer than this (4.5 cm)
#define   KICK_MS           500      // solenoid energised time per kick
#define   KICK_COOLDOWN_MS  1500     // forced gap AFTER a kick before the next
#define   CONFIRM_SAMPLES   2        // consecutive in-range pings before firing
#define   KICK_MAX_ON_MS    600      // HARD safety: coil may NEVER be on longer than this

const unsigned long CAPTURE_PING_MS         = 60;    // re-ping at ~17 Hz (HC-SR04 wants >= 60 ms)
const unsigned int  CAPTURE_ECHO_TIMEOUT_US = 12000; // matches the working standalone test

// Relay polarity. ACTIVE-HIGH on this board (confirmed: active-LOW left the coil
// energised from power-up). Keep 0 unless a relay swap behaves inverted.
#define   RELAY_ACTIVE_LOW  0
#if RELAY_ACTIVE_LOW
  #define RELAY_ON_LEVEL  LOW
  #define RELAY_OFF_LEVEL HIGH
#else
  #define RELAY_ON_LEVEL  HIGH
  #define RELAY_OFF_LEVEL LOW
#endif

// ------------------------------- Gyro ---------------------------------------
Adafruit_BNO055 bno = Adafruit_BNO055(55, 0x28, &Wire2);

// ============================================================================
//  ULTRASONIC RECEIVER  -  US_PORT = Serial3; side index enum is this robot's
//  real orientation B,L,F,R.
// ============================================================================
#define US_SYNC0 0xAA
#define US_SYNC1 0x55
#define US_PORT  Serial3
#define US_BAUD  115200
#define US_STALE_MS 200

enum { US_BACK = 0, US_LEFT = 1, US_FRONT = 2, US_RIGHT = 3 };
enum { US_ST_OK = 0, US_ST_OUT_OF_RANGE, US_ST_HOLD };

struct UltrasonicData {
  uint16_t mm[4];
  uint8_t  status[4];
  uint8_t  seq;
  uint32_t lastUpdateMs;
};
UltrasonicData us = {{2600,2600,2600,2600},{1,1,1,1},0,0};

static uint8_t us_crc8(const uint8_t *d, uint8_t n) {
  uint8_t c = 0x00;
  while (n--) {
    c ^= *d++;
    for (uint8_t b = 0; b < 8; b++)
      c = (c & 0x80) ? (uint8_t)((c << 1) ^ 0x07) : (uint8_t)(c << 1);
  }
  return c;
}

bool ultrasonicPoll(Stream &port) {
  static uint8_t buf[13];
  static uint8_t idx = 0;
  bool got = false;

  while (port.available()) {
    uint8_t b = (uint8_t)port.read();
    if (idx == 0)      { if (b == US_SYNC0) buf[idx++] = b; }
    else if (idx == 1) { if (b == US_SYNC1) buf[idx++] = b; else idx = 0; }
    else {
      buf[idx++] = b;
      if (idx >= 13) {
        idx = 0;
        if (us_crc8(&buf[2], 10) == buf[12]) {
          for (uint8_t i = 0; i < 4; i++)
            us.mm[i] = (uint16_t)buf[2 + 2 * i] | ((uint16_t)buf[3 + 2 * i] << 8);
          for (uint8_t i = 0; i < 4; i++)
            us.status[i] = (buf[10] >> (2 * i)) & 0x03;
          us.seq = buf[11];
          us.lastUpdateMs = millis();
          got = true;
        }
      }
    }
  }
  return got;
}

bool ultrasonicStale() { return (millis() - us.lastUpdateMs) > US_STALE_MS; }
// ============================ end ultrasonic =================================

// ============================================================================
//  LINE PCB RECEIVER  -  Line Teensy on Serial8 (RX8 = pin 34 <- Line TX7/pin 29).
//  Parsed non-blocking like ultrasonicPoll. CRC-8 reuses us_crc8() (poly 0x07,
//  init 0x00) so the Line encoder and this decoder stay symmetric. Frame layout:
//    [0]=0xA5 [1]=0x5A [2]=mask [3..6]=count[0..3] [7]=seq [8]=crc8 over [2..7]
//  mask bits (board order, MUST match the encoder):
//    bit0 = QTR1/RIGHT  bit1 = QTR2/FRONT  bit2 = QTR3/LEFT  bit3 = QTR4/BACK
//  Sync 0xA5/0x5A is deliberately distinct from the ultrasonic link's 0xAA/0x55
//  so a mis-wire can't false-sync one stream onto the other.
// ============================================================================
#define LINE_SYNC0 0xA5
#define LINE_SYNC1 0x5A
#define LINE_PORT  Serial8
#define LINE_BAUD  115200
#define LINE_STALE_MS 200

// QTR board -> robot direction (CONFIRMED). Bit positions MUST match the encoder.
enum { LN_RIGHT_BIT = 0, LN_FRONT_BIT = 1, LN_LEFT_BIT = 2, LN_BACK_BIT = 3 };

struct LineData {
  uint8_t  mask;        // bitmask of boards currently seeing the line
  uint8_t  count[4];    // white-sensor count per board (R,F,L,B) -- diagnostics only
  uint8_t  seq;
  uint32_t lastUpdateMs;
};
LineData line = {0, {0, 0, 0, 0}, 0, 0};

bool linePoll(Stream &port) {
  static uint8_t buf[9];
  static uint8_t idx = 0;
  bool got = false;

  while (port.available()) {
    uint8_t b = (uint8_t)port.read();
    if (idx == 0)      { if (b == LINE_SYNC0) buf[idx++] = b; }
    else if (idx == 1) { if (b == LINE_SYNC1) buf[idx++] = b; else idx = 0; }
    else {
      buf[idx++] = b;
      if (idx >= 9) {
        idx = 0;
        if (us_crc8(&buf[2], 6) == buf[8]) {       // SAME crc8 as the ultrasonic link
          line.mask     = buf[2];
          line.count[0] = buf[3];
          line.count[1] = buf[4];
          line.count[2] = buf[5];
          line.count[3] = buf[6];
          line.seq      = buf[7];
          line.lastUpdateMs = millis();
          got = true;
        }
      }
    }
  }
  return got;
}

bool lineStale() { return (millis() - line.lastUpdateMs) > LINE_STALE_MS; }
bool lineRight() { return (line.mask & (1 << LN_RIGHT_BIT)) != 0; }
bool lineFront() { return (line.mask & (1 << LN_FRONT_BIT)) != 0; }
bool lineLeft()  { return (line.mask & (1 << LN_LEFT_BIT))  != 0; }
bool lineBack()  { return (line.mask & (1 << LN_BACK_BIT))  != 0; }
// ============================ end line receiver ==============================

// ============================================================================
//  GOAL CAMERA RECEIVER  -  OpenMV H7 on Serial2 (Goal_Cam.py is the authority).
//  11-byte frame, parsed non-blocking exactly like ultrasonicPoll:
//    [0]=0xAA [1]=0x55 [2]=flags [3]=attackBearing(i8) [4]=attackDist(u8)
//    [5]=openCornerBear(i8) [6]=keeperBearing(i8) [7]=ownGoalBearing(i8)
//    [8]=ballBearing(i8) [9]=ballDist(u8) [10]=crc8 = CRC-8 (poly 0x07) over bytes 2..9
//  flags: bit0 attackGoalSeen | bit1 ownGoalSeen | bit2 keeperSeen | bit3 ballSeen.
//  The bearing fields are SIGNED int8 (+ = right of forward), matching
//  Goal_Cam.py send_frame(). The ball fields feed the camera+IR fusion (see loop()).
//  >>> Flash the camera and this sketch together: the frame length changed (9 -> 11).
// ============================================================================
#define CAM_SYNC0 0xAA
#define CAM_SYNC1 0x55
#define CAM_PORT  Serial2

struct CameraData {
  bool     attackGoalSeen;
  bool     ownGoalSeen;
  bool     keeperSeen;
  bool     ballSeen;         // camera sees the orange ball (fusion cross-check)
  int8_t   attackBearing;
  uint8_t  attackDist;
  int8_t   openCornerBear;   // THE aim angle
  int8_t   keeperBearing;
  int8_t   ownGoalBearing;
  int8_t   ballBearing;      // + = ball to the robot's right (camera convention)
  uint8_t  ballDist;         // coarse cm, 255 = far/unknown
  uint32_t lastUpdateMs;
};
CameraData cam = {false, false, false, false, 0, 255, 0, 0, 0, 0, 255, 0};
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
void loop() {
  pollIR();
  ultrasonicPoll(US_PORT);
  linePoll(LINE_PORT);                           // line board on Serial8
  if (camPoll(CAM_PORT)) g_camNewFrame = true;   // latch fresh cam frame for the aim outer loop
  pollCapture();
  updateKicker();                                // fires when captured (+ aligned, if REQUIRE_GOAL_TO_KICK)

  unsigned long now = millis();
  if (now - lastLoop < LOOP_MS) return;          // 100 Hz control gate
  float dt = (now - lastLoop) / 1000.0;
  lastLoop = now;

  if (now - g_lastIR > IR_TIMEOUT_MS) g_ballSeen = false;

  float dir = g_ballDir;
  if (IR_DIR_INVERT) dir = -dir;

  // ---- camera + IR ball fusion (IR PRIMARY; camera = short-range check / fallback) ----
  bool ballSeen = g_ballSeen;
#if USE_CAM_BALL_FUSION
  if (cam.ballSeen && !camStale()) {
    // map the camera ball ("+right, 0=front") into the IR `dir` convention (ahead ~ +/-180)
    float camDir  = wrap180(180.0f - (float)cam.ballBearing);
    bool  camNear = (cam.ballDist <= CAM_BALL_NEAR_CM);     // 255 = far/unknown -> not near
    if (!g_ballSeen) {
      dir = camDir; ballSeen = true;                        // IR blind -> chase the camera ball
    } else if (camNear && fabs(wrap180(camDir - dir)) > (float)CAM_BALL_DISAGREE_DEG) {
      dir = camDir;                                         // close range + IR disagrees -> trust camera
    }
  }
#endif

  imu::Vector<3> euler = bno.getVector(Adafruit_BNO055::VECTOR_EULER);
  float heading = euler.x();

  // ---- fused boundary escape (+ optional US-only dodge), then debounce ----
  Sector avoidRaw = boundaryEscapeSector();      // line + US must agree on a side
#if KEEP_OBSTACLE_FALLBACK
  if (avoidRaw == S_NONE) avoidRaw = obstacleDodgeSector();   // lower-priority robot dodge
#endif
  if (avoidRaw != S_NONE) { if (g_avoidStreak < 1000) g_avoidStreak++; }
  else                    { g_avoidStreak = 0; }
  bool   avoidActive = (g_avoidStreak >= AVOID_CONFIRM);

  // ---- high-level state: AIM > AVOID > CHASE > IDLE ----
  bool haveBall = (g_captureHits >= CONFIRM_SAMPLES);

  TopState top;
  if (haveBall)             top = ST_AIM;
  else if (avoidActive)     top = ST_AVOID;
  else if (ballSeen)        top = ST_CHASE;   // ballSeen = IR ring OR camera fallback (fusion)
  else                      top = ST_IDLE;

  // ---- setpoint selection: only AIM overrides the forward heading ----
  if (top == ST_AIM) {
    if (!g_hadBall) {                            // rising edge into possession
      aimHeading = heading;                      // hold here until the goal is seen
      integral = 0; lastError = 0;               // drop chase windup; setpoint just jumped
    }
    if (g_camNewFrame && !camStale() && cam.attackGoalSeen) {
      // outer loop: aim the open corner dead ahead. SIGN = AIM_TURN_SIGN (bench-verify).
      aimHeading = wrap180(heading + AIM_TURN_SIGN * (float)cam.openCornerBear);
    }
    setpoint = aimHeading;                        // goal lost -> aimHeading untouched -> holds last good heading
  } else {
    setpoint = forwardHeading;
  }
  g_camNewFrame = false;
  g_hadBall = haveBall;

  // ---- heading-hold PID (UNCHANGED maths) ----
  float correction = 0;
  if (HOLD_HEADING) {
    float error   = wrap180(heading - setpoint);
    integral += error * dt;
    integral  = constrain(integral, -200, 200);
    float deriv = (error - lastError) / dt;
    lastError = error;
    correction = K_SIGN * (Kp * error + Ki * integral + Kd * deriv);
    correction = constrain(correction, -MAX_CORRECTION, MAX_CORRECTION);
  }

  // ---- act ----
  switch (top) {
    case ST_AIM:
      driveSector(S_FWD, AIM_FORWARD_BIAS, correction);   // spin in place to face the open corner
      break;
    case ST_AVOID:
      driveSector(avoidRaw, AVOID_SPEED, correction);
      break;
    case ST_CHASE:
      driveSector(classify(dir), DRIVE_SPEED, correction);
      break;
    case ST_IDLE:
    default:
      stopMotors();
      integral = 0; lastError = 0;
      break;
  }

  // ---- debug (USB Serial Monitor) ----
  static unsigned long lastPrint = 0;
  if (now - lastPrint > 150) {
    lastPrint = now;
    const char* topNm[] = { "IDLE", "CHASE", "AVOID", "AIM" };
    const char* ks[]    = { "IDLE", "KICKING", "COOLDOWN" };

    Serial.print("[");   Serial.print(topNm[top]); Serial.print("] ");
    Serial.print("dir="); Serial.print(dir, 1);
    Serial.print(" US F="); Serial.print(us.mm[US_FRONT]);
    Serial.print(" R=");    Serial.print(us.mm[US_RIGHT]);
    Serial.print(" B=");    Serial.print(us.mm[US_BACK]);
    Serial.print(" L=");    Serial.print(us.mm[US_LEFT]);
    Serial.print(ultrasonicStale() ? "(STALE)" : "");
    // ---- line PCB flags (fused escape needs line + US to agree) ----
    Serial.print(" | LN[");
    Serial.print(lineRight() ? "R" : "-");
    Serial.print(lineFront() ? "F" : "-");
    Serial.print(lineLeft()  ? "L" : "-");
    Serial.print(lineBack()  ? "B" : "-");
    Serial.print("]");
    Serial.print(lineStale() ? "(STALE)" : "");
    Serial.print(" lseq="); Serial.print(line.seq);
    Serial.print(" avS=");  Serial.print(g_avoidStreak);
    // ---- kicker diagnostics: relay vs capture at a glance ----
    Serial.print(" | cap="); Serial.print(g_captureMm);
    Serial.print("mm hits="); Serial.print(g_captureHits);
    Serial.print(" relay=");  Serial.print(g_solenoidOn ? "ON" : "off");
    Serial.print("/");        Serial.print(ks[g_kick]);
    // ---- camera + aim ----
    Serial.print(" | CAM g="); Serial.print(cam.attackGoalSeen ? 1 : 0);
    Serial.print(" open=");    Serial.print(cam.openCornerBear);
    Serial.print(" ball=");    Serial.print(cam.ballSeen ? 1 : 0);
    Serial.print("@");         Serial.print(cam.ballBearing);
    Serial.print("/");         Serial.print(cam.ballDist);
    Serial.print(camStale() ? "(STALE)" : "");
    Serial.print(" KICKGATE="); Serial.print(goalAimReady() ? 1 : 0);
    Serial.print(" aim=");      Serial.print(setpoint, 1);
    Serial.print(" hdg=");      Serial.print(heading, 1);
    Serial.print(" corr=");     Serial.println(correction, 1);
  }
}

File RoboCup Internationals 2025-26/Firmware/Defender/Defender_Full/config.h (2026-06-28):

#ifndef CONFIG_H
#define CONFIG_H
#include <Arduino.h>

// ============================================================================
//  Defender_Full / config.h  -  defender knobs + the Line PCB contract.
//
//  Sensor roles: the BACK ULTRASONIC is the continuous box standoff (depth PID);
//  the LINE ring (Serial8, 9-byte A5/5A mask frame) marks the box EDGES - the
//  FRONT board flags the up-field box line (up-field limit) and the RIGHT/LEFT
//  boards flag the side lines (corner limits). Ultrasonics also centre laterally
//  and home in RECOVER.
//
//  >>> BENCH-VERIFY the sign fix-points: IR_DIR_INVERT, the US enum (in the
//      .ino), and the Line board->direction mapping (LN_*_BIT + linePoll()).
// ============================================================================

// ---- feature flags (all default OFF; the sketch runs with none of them) ----
#define USE_CAMERA 0          // OpenMV goal cam on Serial1 (11-byte AA 55 frame)
#define USE_COMMS  0          // GO/STOP referee inputs on A12/A13
#define USE_OLED   0          // SSD1306 status mirror on Wire (pins 18/19)

// ---- IR ball bearing -> lateral ----
#define IR_DIR_INVERT 0       // set 1 if a ball on the RIGHT reads NEGATIVE

// ---- Lateral PID: input = ball bearing (deg, front=0 right=+ left=-), sp 0, out vx ----
#define KP_LAT 3.0f
#define KI_LAT 0.0f
#define KD_LAT 0.15f
#define LATERAL_MAX_VX 255

// ---- Depth PID: output vy. Input = back-ultrasonic standoff (the continuous datum) ----
#define KP_DEPTH 1.20f
#define KI_DEPTH 0.0f
#define KD_DEPTH 0.10f
#define DEPTH_MAX_VY 200
#define BACK_STANDOFF_MM 220  // ultrasonic fallback/cross-check standoff (US_BACK)

// ---- GUARD/RECOVER lateral centring (still ultrasonic: line only marks edges) ----
#define KP_CENTER 0.50f

// ---- Ultrasonic lateral limits (cross-check of the line edges) ----
#define SIDE_LIMIT_MM 140

// ---- Heading-hold behaviour (fixes idle drift) ----
// The BNO055 in IMUPLUS mode has no magnetometer, so its yaw DRIFTS. Holding
// heading continuously while parked makes the keeper slowly spin to chase that
// drift. So: ignore tiny errors, and relax (stop) when nothing is commanded.
#define HEADING_DEADBAND_DEG 3.0f  // don't correct heading errors smaller than this
#define IDLE_HOLD_HEADING    0     // 0 = relax heading when parked (no idle creep, like
                                   //     the attacker); re-locks the instant it moves.
                                   // 1 = keep actively holding even when stationary (only
                                   //     if your heading reference does NOT drift).

// ---- INTERCEPT (folded into TRACK) ----
#define INTERCEPT_RATE_DPS 120.0f
#define INTERCEPT_BOOST    1.6f

// ---- CLEAR ----
#define CLEAR_PUSH_VY  200
#define CLEAR_PUSH_MS  450

// ---- RECOVER ----
#define RECOVER_TOL_MM     60
#define RECOVER_TIMEOUT_MS 1200

// ============================================================================
//  LINE PCB CONTRACT  (Serial8)  -  9-byte A5/5A mask frame, byte-identical to
//  the one the attacker decodes (one shared line link across both robots):
//
//    [0]=0xA5 [1]=0x5A [2]=mask [3..6]=count[0..3] [7]=seq [8]=crc8 over [2..7]
//      mask  : bit0 RIGHT, bit1 FRONT, bit2 LEFT, bit3 BACK (board "sees line").
//      count : per-board white-channel count (diagnostics only).
//      seq   : uint8 packet counter (gaps => dropped packets).
//      crc8  : poly 0x07, init 0x00, over the 6 payload bytes [2..7] - the SAME
//              algorithm as the ultrasonic link, so us_crc8() is reused as-is.
//
//  The keeper uses the FRONT flag (up-field box line) and RIGHT/LEFT flags (side
//  lines) as hard edge limits; the back ultrasonic gives the continuous standoff.
//  The bit order lives in the .ino (LN_*_BIT) and MUST match the Line encoder.
// ============================================================================
#define LINE_BAUD           115200
#define LINE_STALE_MS       200   // no good frame this long -> distrust the line
// Safety cross-check (the line marks the FRONT/side box lines, the back US measures
// the OWN-goal wall - different datums, so we don't compare them directly). Instead:
// regardless of what the line says, never drive toward the own goal (vy < 0) when the
// back ultrasonic shows the own-goal wall closer than this. Stops a bad reading from
// reversing the keeper into its own net.
#define BACK_WALL_SAFE_MM   90

// ---- camera (optional, Serial1, default OFF) ----
#if USE_CAMERA
  #define CAM_PORT      Serial1
  #define CAM_BAUD      115200
  #define K_CAM_TRIM    0.02f
  #define CAM_TRIM_MAX  20.0f
  #define CAM_STALE_MS  300
  #define CAM_AIM_GAIN  0.30f
#endif

// ---- comms GO/STOP (optional, default OFF) ----
#if USE_COMMS
  #define COMMS_GO_PIN     A12
  #define COMMS_STOP_PIN   A13
  #define COMMS_ACTIVE_LOW 1
#endif

#endif // CONFIG_H

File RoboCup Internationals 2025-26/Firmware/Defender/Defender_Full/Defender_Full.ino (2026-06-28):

/*
  ============================================================================
  DEFENDER (goalkeeper) - FULL (with Line PCB)  -  Main Teensy 4.1
  ----------------------------------------------------------------------------
  Goalkeeper that rides the edge of the goal area ("the D"). Sensor roles:
     back ultrasonic  -> CONTINUOUS standoff (depth PID input)
     line ring (Serial8) -> box-EDGE limits: the FRONT board flags the up-field
                            box line (don't drift up-field past it); RIGHT/LEFT
                            boards flag the side lines (corner limits).
  A reflectance ring can only tell you a board is OVER the line, not a continuous
  distance, so the ULTRASONIC (not the line) gives the smooth standoff while the
  line hard-stops the keeper at the box edges. The ultrasonics also centre the
  keeper laterally, give a back-wall safety cross-check, and home it in RECOVER.

  The Line receiver decodes the SAME non-blocking 9-byte A5 5A mask/counts frame
  the attacker decodes (see config.h LINE_* and linePoll() below) - one shared
  line contract across both robots.

  BUILD: Arduino IDE, Tools > Board > Teensy 4.1, USB Type "Serial". Libraries:
         Adafruit BNO055 + Adafruit Unified Sensor (and SSD1306+GFX iff USE_OLED).

  Wiring adds, over the NoLine build:
    Line PCB : Serial8 (RX8 = pin 34 <- Line board TX7/pin 29). 115200, 9-byte
               A5/5A mask frame. (Line Teensy TX is 3.3V -> no shifter into pin 34.)
  ============================================================================
*/

#include <Wire.h>
#include <Adafruit_Sensor.h>
#include <Adafruit_BNO055.h>
#include <utility/imumaths.h>
#include "config.h"

#if USE_OLED
  #include <Adafruit_GFX.h>
  #include <Adafruit_SSD1306.h>
#endif

// ----------------------------------------------------------------------------
// Drive base: motor pins, sign tables, heading PID, IR + ultrasonic parsers.
// ----------------------------------------------------------------------------

// ----------------------------- Motor pins -----------------------------------
const int SLEEP_PIN = 6;
const int M1_EN = 2,  M1_DIR = 3;
const int M2_EN = 4,  M2_DIR = 5;
const int M3_EN = 10, M3_DIR = 9;
const int M4_EN = 12, M4_DIR = 11;

const int turnSign[4] = { -1, +1, -1, +1 };

enum Sector { S_FWD = 0, S_RIGHT = 1, S_LEFT = 2, S_BACK = 3, S_NONE = 4 };

// Goalkeeper state-machine states. Declared up HERE (not beside the state
// machine below) so the type precedes the Arduino auto-generated prototypes,
// which the IDE injects just before the first function definition (us_crc8).
// Otherwise stateName(DefState)'s generated prototype names DefState before it
// exists and the sketch fails to compile.
enum DefState { ST_GUARD = 0, ST_TRACK, ST_CLEAR, ST_RECOVER, ST_STOPPED };

const int moveSign[4][4] = {
  /* S_FWD   */ { -1, -1, -1, -1 },
  /* S_RIGHT */ { +1, -1, -1, +1 },
  /* S_LEFT  */ { -1, +1, +1, -1 },
  /* S_BACK  */ { +1, +1, +1, +1 },
};

// // ---- STRAFE_FIX (use if left/right spin instead of sliding sideways) ----
// const int moveSign[4][4] = {
//   /* S_FWD   */ { -1, -1, -1, -1 },
//   /* S_RIGHT */ { -1, +1, +1, -1 },
//   /* S_LEFT  */ { +1, -1, -1, +1 },
//   /* S_BACK  */ { +1, +1, +1, +1 },
// };

#define     HOLD_HEADING  1
// IR_DIR_INVERT moved to config.h.

float       Kp = 6.0, Ki = 0.0, Kd = 0.5;
const float MAX_CORRECTION = 200;
float       K_SIGN = -1.0;

const unsigned long LOOP_MS       = 10;
const unsigned long IR_TIMEOUT_MS = 250;

const int CAPTURE_TRIG = 20;
const int CAPTURE_ECHO = 21;
const int SOLENOID_PIN = 22;

#define   CAPTURE_BALL_MM   50
#define   KICK_DELAY_MS     250
#define   KICK_MS           100
#define   KICK_COOLDOWN_MS  2000

const unsigned long CAPTURE_PING_MS         = 25;
const unsigned int  CAPTURE_ECHO_TIMEOUT_US = 1800;

#define   RELAY_ACTIVE_LOW  0
#if RELAY_ACTIVE_LOW
  #define RELAY_ON_LEVEL  LOW
  #define RELAY_OFF_LEVEL HIGH
#else
  #define RELAY_ON_LEVEL  HIGH
  #define RELAY_OFF_LEVEL LOW
#endif

Adafruit_BNO055 bno = Adafruit_BNO055(55, 0x28, &Wire2);

// ============================ ULTRASONIC ====================================
#define US_SYNC0 0xAA
#define US_SYNC1 0x55
#define US_PORT  Serial3
#define US_BAUD  115200
#define US_STALE_MS 200

enum { US_BACK = 0, US_LEFT = 1, US_FRONT = 2, US_RIGHT = 3 };
enum { US_ST_OK = 0, US_ST_OUT_OF_RANGE, US_ST_HOLD };

struct UltrasonicData {
  uint16_t mm[4];
  uint8_t  status[4];
  uint8_t  seq;
  uint32_t lastUpdateMs;
};
UltrasonicData us = {{2600,2600,2600,2600},{1,1,1,1},0,0};

static uint8_t us_crc8(const uint8_t *d, uint8_t n) {
  uint8_t c = 0x00;
  while (n--) {
    c ^= *d++;
    for (uint8_t b = 0; b < 8; b++)
      c = (c & 0x80) ? (uint8_t)((c << 1) ^ 0x07) : (uint8_t)(c << 1);
  }
  return c;
}

bool ultrasonicPoll(Stream &port) {
  static uint8_t buf[13];
  static uint8_t idx = 0;
  bool got = false;
  while (port.available()) {
    uint8_t b = (uint8_t)port.read();
    if (idx == 0)      { if (b == US_SYNC0) buf[idx++] = b; }
    else if (idx == 1) { if (b == US_SYNC1) buf[idx++] = b; else idx = 0; }
    else {
      buf[idx++] = b;
      if (idx >= 13) {
        idx = 0;
        if (us_crc8(&buf[2], 10) == buf[12]) {
          for (uint8_t i = 0; i < 4; i++)
            us.mm[i] = (uint16_t)buf[2 + 2 * i] | ((uint16_t)buf[3 + 2 * i] << 8);
          for (uint8_t i = 0; i < 4; i++)
            us.status[i] = (buf[10] >> (2 * i)) & 0x03;
          us.seq = buf[11];
          us.lastUpdateMs = millis();
          got = true;
        }
      }
    }
  }
  return got;
}

bool ultrasonicStale() { return (millis() - us.lastUpdateMs) > US_STALE_MS; }
// ============================ end ultrasonic =================================

// ------------------------------ IR UART -------------------------------------
#define IR_SERIAL Serial4
#define IR_BAUD   115200
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

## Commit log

2026-06-27 Add RoboCup Internationals 2025-26: firmware, PCB, CAD, docs
    New season folder alongside Regionals/Nationals. Includes the cleaned
    current firmware (attacker, defender, IR, line, ultrasonic, motor),
    KiCad PCB sources + fab zips, Fusion/print CAD tracked via Git LFS,
    and README plus technical docs. No existing files were changed.
    [2025_Lightweight_-_Side_Wall.STL, 2025_Lightweight_-_Wheel_Back.STL, 2025_Lightweight_-_Wheel_Front.STL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]
2026-06-28 Normalize names to Title case; reorganize CAD prints by subsystem; add root README + LICENSE
    - Capitalize all category folders (CAD, PCB, Firmware, Docs, Legacy) and their
    subfolders (IR, Main, Line, Power, Ultrasonic, Fusion, Wiring, Fabrication,
    IR_Ball_Sensor, Line_Sensor, Motor_Current); normalize the lowercase Arduino
    sketch folders and their matching .ino files.
    - CAD: rename print/ -> Printable/ and regroup the STLs by subsystem
    (Chassis, Drive, Ball_Capture, Sensor_Mounts).
    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
    [2025_Lightweight_-_Side_Wall.STL, 2025_Lightweight_-_Wheel_Back.STL, 2025_Lightweight_-_Wheel_Front.STL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]
2026-06-28 Defender line-edge keeper + camera/IR ball fusion; add BOM and block diagram
    Make the firmware match the documented behaviour (close the over-claims):
    - Defender (Defender_Full): decode the real 9-byte A5/5A line mask frame - the same
    one the attacker already uses - instead of the dead 8-byte depth frame nothing
    produced. Standoff now comes from the back ultrasonic (continuous); the FRONT line
    flag is the up-field box-edge limit and RIGHT/LEFT flags are corner limits. The
    LINE_DEPTH_SETPOINT depth contract is removed.
    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
    [VVS_Ballers_BOM.xlsx]
2026-06-28 Add inter-robot role switching (nRF24L01+ RobotLink); tidy IR distance notes
    - Firmware/Comms/RobotLink: an nRF24L01+ (2.4 GHz, peer-to-peer) role-arbitration
    module. One firmware on both robots; partner alive -> play base role, partner
    lost -> cover the goal as keeper. Demote is immediate; promote back waits for a
    referee GO edge (or a timed resume if GO is not wired). Fail-safe: keeper before
    the first heartbeat, and the static base role if the radio is absent. House
    framing reused (2-byte sync + rolling seq + CRC-8 poly 0x07). Uses SPI1
    (26/39/27, since 11/12 are Motor 4); CE/CSN on 30/31; all pins bench-flagged.
    Includes a role-dispatcher example and an integration + bench-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
    [Code2_Calibrated.ino, IRSensor.cpp, RobotLink.h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]
2026-06-28 RobotLink: remove the module-level status caveat wording
    Keep the per-pin >>> BENCH-VERIFY wiring notes and the fail-safe behaviour; only the
    module status lines are removed (RobotLink.h, the Comms README, and the dispatcher
    example).
    [RobotLink.h, RoleDispatch_Example.ino]
2026-06-28 RobotMain: combined firmware that runs either role live (RobotLink dispatch)
    One sketch flashed to both robots. RobotMain.ino calls RobotLink.update() each loop and
    runs attackerLoop() or defenderLoop() per the arbitrated role, safe-stopping the outgoing
    role (motors + solenoid) on a switch. The two behaviour bodies are generated from the
    canonical Attacker/Defender sketches into AttackerRole.cpp / DefenderRole.cpp, each wrapped
    in an anonymous namespace so their shared globals and clashing defines stay isolated;
    RobotLink is bundled in the folder. The standalone Attacker/Defender sketches are unchanged
    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
2026-06-28 Close 3 TDP accuracy gaps in the repo: DRVOFF wiring, camera CRC-8, drive normalisation
    1. Motor-current: stale comments said DRVOFF was tied to GND (so the Nano could not coast
    a stalled motor). Updated to the as-built wiring - DRVOFF lifted onto the Nano D2-D5 -
    in both Motor_Current sketches and HOW_IT_WORKS; removed the resolved board-mod caveat.
    2. Camera link now carries a real CRC-8 (poly 0x07) instead of a modular sum: Goal_Cam.py
    and Goal_Cam_Ball.py compute crc8() over the payload, and the attacker camPoll + the
    defender cameraPoll verify it. IR is documented precisely as delimited ASCII with no
    checksum. Docs updated (the binary links - ultrasonic, line, camera - ar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
    [AttackerRole.cpp, Attacker_Chase_Aim_Kick_Line.ino, DefenderRole.cpp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]
2026-07-05 Add competition media: TDP, poster, interview deck, and a full photo gallery
    - Docs/ gains TDP.pdf, RoboCup_Internationals_Poster.png, and the group-interview
    deck (PPTX).
    - Docs/Images/ now holds the photo gallery, organised as Robots / Electronics /
    Mechanical / Diagrams / Team (46 files; iPhone HEIC photos converted to
    web-viewable JPG at max 1920 px).
    - READMEs: hero photo of both robots, a Competition documents & media section with
    the poster embedded, a five-board PCB render strip in Electronics, the team photo,
    and media links on the repo front page. The TDP video (154 MB) is linked as a
    GitHub Release asset rather than stored in-repo.
    - Corrected the remaining 9-byte came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
2026-07-18 docs: trim Team section to the current roster
